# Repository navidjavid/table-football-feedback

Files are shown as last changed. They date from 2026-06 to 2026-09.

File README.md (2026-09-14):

# Table Football Feedback System ⚽

A smart foosball table built for the UbiLab university course. The table
identifies players by RFID, tracks the ball and score in real time, shows
match status on an on-cabinet LCD per side, and streams everything live
to a web dashboard hosted on a Raspberry Pi 4 — no internet connection
required, the Pi runs its own WiFi hotspot.

This repo contains **two independently-runnable projects**:

| Part | Where | Runs on | Language |
|---|---|---|---|
| Embedded firmware | `src/`, `include/`, `lib/` | Raspberry Pi Pico 2 W ×2 | C (Pico SDK) |
| Server + dashboard | `server/` | Raspberry Pi 4 | Python (Flask) |

They talk to each other over MQTT/WiFi — but the two Picos also talk
**directly to each other** over a shared I2C bus, so registration keeps
working even with no Pi/WiFi present at all (see §3).

---

## 1. System overview

```
 ┌──────────────┐                 ┌──────────────────────┐   ┌──────────────────────┐
 │ Ball tracker │────I2C (shared)▶│  Side A PCB           │   │  Side B PCB           │
 │ (external,   │────────────────▶│  Pico 2W + RFID +     │◀─▶│  Pico 2W + RFID +     │
 │  other team) │  both boards    │  display (PRIMARY)    │I2C│  display (SECONDARY)  │
 └──────────────┘  listen         └───────────┬──────────┘   └──────────┬────────────┘
                                               │ MQTT/WiFi                │ MQTT/WiFi
                                               ▼                          ▼
                                   ┌─────────────────────────────────────────────┐
                                   │              Raspberry Pi 4                  │
                                   │  WiFi hotspot "TableFootball"                │
                                   │  Mosquitto MQTT broker                       │
                                   │  Flask web app (SSE) + SQLite (WAL)          │
                                   └───────────────────┬───────────────────────────┘
                                                       │ HTTP / SSE
                                                       ▼
                                           Any phone/laptop on the hotspot —
                                           live dashboard, player profiles,
                                           admin panel, tournament brackets
```

**Two independent PCBs, one per side** — each has its own Pico 2 W, PN532
RFID reader, and EA DOGL128 display. Both boards listen to the same
shared I2C bus from the ball-tracker hardware. Exactly one board is
configured `PICO_ROLE_PRIMARY` (owns reporting ball position/score/state
to the Pi); the other only reports its own side's RFID taps + heartbeat —
this avoids the server ever getting duplicate/racing data from both
boards for the same table.

**Data flow, end to end:**

1. A player taps an RFID card on either side's own PN532 reader.
2. That board reads the UID over SPI, registers it locally (own side's
   roster, up to 2 players for 2v2), and:
   - broadcasts it directly to the **sibling board** over the shared I2C
     bus (a board briefly becomes I2C master to send this — see §3),
     so the other side learns about it **with no Pi/WiFi involved**;
   - publishes it to the Pi over MQTT, which is authoritative for
     identity/history — it resolves the UID against its own SQLite
     database (or creates a guest), decides when the match should
     start, and echoes the resolved name back.
3. The primary board republishes ball x/y/speed/score at ~12 Hz from the
   shared I2C feed; the dashboard renders this as a moving dot on a mini
   pitch.
4. Goals are detected locally (baseline-diffed against the ball
   tracker's own score fields, not trusted directly) on **both** boards
   independently, each updating its own display; the primary board's
   published state drives the dashboard's "GOAL!" animation.
5. At game end, the Pi saves the full match (mode, score, players,
   fastest shot, winner) to SQLite — shows up in player profiles, match
   history, and tournament brackets.
6. If a table gets stuck in `GAME_PLAYING` with no update for 45s (a
   board crashed/rebooted mid-match), the Pi's own watchdog auto-abandons
   it — so a later reconnect never resumes a long-dead game.

`[PICTURE: photo of the assembled table — both enclosures, PN532s, LCDs visible]`

---

## 2. Physical components & wiring

### Hardware list (×2, one set per side)

- **Raspberry Pi Pico 2 W** — WiFi, RFID, display, local game logic
- **PN532 NFC/RFID reader module**, configured in **SPI mode** (DIP
  switches: SEL0=OFF, SEL1=ON)
- **EA DOGL128L-6** graphic LCD, 128×64, reflective (no backlight),
  driven with **bit-banged SPI** (hardware SPI caused timing issues on
  this clone)
- A custom 3D-printed enclosure (front panel + back shell,
  `hardware/enclosure/` in a sibling directory to this repo — not
  version-controlled here) with a display window and a cable
  pass-through for the shared I2C bus
- RFID cards, one per player — UID is the player's identity end to end

Plus shared infrastructure:
- An external **ball-tracker** (built by another team) that writes ball
  position packets over I2C to both boards
- **Raspberry Pi 4** (any RAM tier) + microSD (16 GB+) + 5V/3A USB-C
  power supply — runs the WiFi hotspot, MQTT broker, and Flask server

`[PICTURE: each component individually — Pico board, PN532 module with DIP switches labeled, EA DOGL128 display, an assembled enclosure, an RFID card]`

### Real-world table dimensions

The physical table is **140 cm long × 76 cm wide**. The dashboard's
field visualization is intentionally drawn at this exact 140:76 aspect
ratio (`server/static/style.css`, `.field { aspect-ratio: 140 / 76; }`),
and ball coordinates are normalized to a 0–1000 × 0–500 grid before
being sent over MQTT so the same ratio holds end to end.

`[PICTURE: top-down schematic of the table with dimensions labeled, goal positions marked]`

### Pin connections — per side board

| Component | Signal | Pico GPIO | Physical pin |
|---|---|---|---|
| PN532 (SPI1) | SCK | GP10 | 14 |
| | MOSI | GP11 | 15 |
| | MISO | GP12 | 16 |
| | NSS/CS | GP13 | 17 |
| | RSTO | GP15 | 20 |
| | VCC / GND | 3.3V / GND | 36 / 38 |
| EA DOGL128 (bit-bang SPI) | SI (MOSI) | GP19 | 25 |
| | SCL (SCK) | GP18 | 24 |
| | A0 (data/cmd) | GP20 | 26 |
| | RST | GP21 | 27 |
| | CS1B | GP17 | 22 |
| Shared ball-tracker I2C bus | SDA | GP4 | 6 |
| | SCL | GP5 | 7 |

The display additionally needs **9 capacitors** for its internal charge
pump (5×1µF on V0–V4, 3×1µF on the CAP1/2/3 chain, 4.7µF on VOUT) — see
[`docs/hardware_connections.md`](docs/hardware_connections.md) for the
full, datasheet-verified capacitor wiring table; it will not power on
without them, and the topology is easy to get wrong (this project did,
once, before it was corrected).

The shared I2C bus needs **4.7kΩ pull-ups** on both SDA and SCL, and all
boards (both side PCBs + the ball tracker) must share a common GND.

`[PICTURE: wiring diagram / breadboard schematic showing all of the above]`

### PCB layout (KiCad)

The per-side board above is laid out in KiCad as
[`PCB/ubi_lab.kicad_sch`](PCB/ubi_lab.kicad_sch) +
[`PCB/ubi_lab.kicad_pcb`](PCB/ubi_lab.kicad_pcb) — open both together in
**KiCad 10**. It's a two-layer, 1.6 mm board with a **76 × 68 mm** outline,
carrying a socket footprint for a Pico-family board on the back plus three
connectors: `J1` (8-pin, PN532, fed from the board's 3.3V rail), `J2`
(40-pin, EA DOGL128L-6), and `J3` (4-pin, labeled `I2C_SIMULATOR` — VBUS/
GND/SDA/SCL on pins 1–4, for bench-testing against `test_i2c_simulator`
before the real ball tracker is wired in). `R1`/`R2` are the 4.7kΩ I2C
pull-ups called out above.

A few things to confirm before sending a board to fab or assembling one:

- The custom `ubi_lab:RaspberryPi_Pico_Socket_THT` footprint is embedded
  in the PCB, but its source library isn't in this repo — KiCad will need
  it to re-sync the PCB from schematic edits.
- The symbol/footprint say `RaspberryPi_Pico_W`, and the socket
  footprint's own description also mentions Pico 2 W — double check the
  exact variant, header orientation, and display-module/connector mating
  against the physical parts on hand.
- Schematic and PCB disagree on some capacitor reference designators
  (e.g. a PCB ref like `1µF7` vs. the schematic's `C` prefix) — run
  KiCad's ERC/DRC and reconcile annotations before fabrication.

### Software-side bus configuration

| Parameter | Value |
|---|---|
| SPI1 (PN532) speed | 1 MHz |
| I2C0 speed | 9600 baud |
| I2C slave address | `0x42` (shared by both side boards — see §3) |
| Display contrast | `0x13` |

Full pinout reference: [`docs/hardware_connections.md`](docs/hardware_connections.md).

---

## 3. Embedded firmware (Raspberry Pi Pico)

Built with the **Pico SDK 2.2.0**, targeting `pico2_w`, using **lwIP in
polling mode** (`NO_SYS=1` — no RTOS, everything runs from one
`while(true)` loop with `cyw43_arch_poll()` keeping WiFi/MQTT alive).

The **same firmware image** runs on both side boards — which side/role a
board plays is a compile-time config block at the top of `src/main.c`:

```c
#define MY_SIDE            'A'   // 'A' on this board, 'B' on the other
#define PICO_ROLE_PRIMARY  1     // 1 on exactly ONE board
#define PICO_ID    "pico-side-a" // must be unique per board
```

Flip these three, rebuild, and flash the other board.

### Source layout

| File | Responsibility |
|---|---|
| `src/main.c` | WiFi connect (with on-screen boot status), MQTT init, main loop |
| `src/rfid_handler.c` + `lib/pn532/pn532.c` | PN532 SPI driver + tap-debounce state machine |
| `src/i2c_comms.c` | Ball-position ring buffer **and** the offline peer-tap link between the two boards (see below) |
| `src/game_logic.c` | Local game state machine (`GAME_WAITING` → `GAME_PLAYING` → `GAME_OVER`), up to 2 players/side, goal detection, fastest-shot tracking |
| `src/display_manager.c` + `lib/ea_dogl128/` | Renders game state to the on-cabinet LCD |
| `src/pico_mqtt.c` + `include/pico_mqtt.h` | lwIP raw MQTT client wrapper — connects (with a Last-Will-Testament), publishes heartbeat/RFID/state/ball, subscribes to player/sync/rfid/cmd |
| `lwipopts.h` | lwIP buffer/pool sizing — tuned specifically to survive MQTT's keep-alive timers (see bug notes below) |

### Offline board-to-board link (no Pi/WiFi required)

Both boards need to know about **both** sides' registered players, but
cross-board MQTT sync only works when the Pi is reachable — and the PCBs
are already assembled with no spare wiring for a dedicated link. Instead,
the two boards share the same physical I2C bus the ball tracker uses:

- The ball tracker is the bus's only permanent master, always **writing**
  to address `0x42`; both boards listen there as slaves (a
  write-only-broadcast trick — see `include/i2c_comms.h`).
- When a card taps on one side, that board briefly becomes the I2C
  master itself (`i2c_slave_deinit()` → write → `i2c_slave_init()`,
  the Pico SDK's documented idiom for this) and writes a short 9-byte
  message to that same shared address. The sibling board, still
  listening normally, receives it — distinguished from ball-data packets
  purely by a different sync header.
- Standard I2C multi-master arbitration handles the rare case of
  colliding with the ball tracker's own write; a lost attempt is simply
  dropped (a tap is a one-off, low-frequency event, so this is an
  accepted low-stakes failure mode).

MQTT's `/rfid` topic (subscribed by both boards) is a second, best-effort
channel carrying the same information when the Pi is present — the I2C
link is what makes registration work **at all** with no Pi/WiFi.

### RFID → MQTT + I2C flow

1. `rfid_handler_scan()` polls the PN532 over SPI; a debounce window
   avoids re-firing on the same card sitting on the reader.
2. On a fresh tap, `game_lookup_player()` checks a small hardcoded
   table of known UIDs → names (demo roster: Alice, Bob, Carol, Dave)
   purely so the **local LCD** can show a name immediately.
3. The tap is registered locally (own side, next open slot), broadcast
   to the sibling board over I2C, and published to
   `tablefootball/table/<id>/rfid`. The Pi is the identity authority —
   it resolves the UID against its own SQLite `players` table and
   echoes the resolved name + slot back over
   `tablefootball/pico/<id>/player`.

### Ball tracking → MQTT flow

The ball tracker writes a 20-byte binary packet over I2C
(`SYNC_A SYNC_B x y prev_x prev_y field_w field_h speed possession
score_a score_b`, see `include/i2c_comms.h`). `i2c_comms_poll()` drains
this from a ring buffer filled by an I2C-slave interrupt handler — the
same ring buffer also carries the peer-tap messages above, distinguished
by sync header. `game_update()` diffs the embedded score against its
last-seen baseline to detect goals (rather than trusting the raw score
directly), and the ball position is rescaled to a 0–1000×0–500 grid
before the **primary** board publishes it on
`tablefootball/table/<id>/ball` at roughly 12 Hz.

`[PICTURE: serial console screenshot showing RFID tap + MQTT publish logs]`

### MQTT topics

**Published by each Pico:**

| Topic | Rate | Payload |
|---|---|---|
| `tablefootball/pico/<id>/heartbeat` | every 5s | online status, IP, firmware version, uptime |
| `tablefootball/table/<id>/rfid` | on tap | UID, side, slot |
| `tablefootball/table/<id>/state` | ~1/s, primary only | score, mode, fastest shot, winner (on GAME_OVER) |
| `tablefootball/table/<id>/ball` | ~12 Hz, primary only | x, y, speed |
| `tablefootball/pico/<id>/status` | LWT | `online:false`, set on disconnect |

**Subscribed by each Pico** (the Pi is source of truth for identity/state,
but the board must never depend on it being reachable — see §"Offline
board-to-board link" above):

| Topic | Purpose |
|---|---|
| `tablefootball/pico/<id>/player` | Authoritative name for a resolved tap |
| `tablefootball/table/<id>/sync` | Full roster + score/state snapshot (retained) — reconciles admin-driven registration changes, which produce no RFID tap at all |
| `tablefootball/table/<id>/rfid` | The sibling board's own taps (same topic it publishes to) |
| `tablefootball/pico/<id>/cmd` | Admin-panel commands: identify / reset_match / clear_players / show_message |

### Bugs worth knowing about (and their fixes)

These came up while building this firmware and are good examples of how
easy it is to silently break shared resources or drop a field across a
protocol boundary:

1. **I2C bytes dropped during every RFID scan.** `rfid_handler.c`
   disables `I2C0_IRQ` for the duration of `pn532_read_card()` to keep
   the I2C slave handler from interfering with SPI timing. But PN532's
   internal "wait for ready" polling loop can run for up to ~250ms per
   scan, and the IRQ stayed off that whole time — so every ball-position
   byte arriving during a card scan was lost. **Fix:** the wait loop now
   masks `I2C0_IRQ` only for the few microseconds of the actual SPI
   status read, unmasked during each 1ms sleep in between.
2. **`*** PANIC *** sys_timeout` crash.** lwIP's default
   `MEMP_NUM_SYS_TIMEOUT` pool wasn't enough once MQTT's keep-alive timer
   joined it. **Fix:** `lwipopts.h` explicitly sets it to 16.
3. **Admin dashboard commands did nothing on real hardware.** The server
   published to `tablefootball/pico/<id>/cmd` from the start, but the
   firmware never subscribed to that topic at all — every "Identify" /
   "Reset Match" / "Message" button silently no-op'd. Fixed by actually
   subscribing and dispatching (see `on_pi_cmd()` in `main.c`).
4. **A 2v2 name-correction bug.** The Pi's per-tap name resolution always
   corrected roster slot 1, no matter which slot the response was
   actually about — invisible in 1v1 (only one slot exists), but
   resolving a *second* player's name would silently overwrite the
   first player's name too. Fixed by having the server include (and the
   firmware use) the actual slot number in that message.
5. **A NULL-pointer crash with no Pi present.** If the Pi's hotspot
   simply doesn't exist at boot, `mqtt_app_init()` is never called, so
   the internal MQTT client stays `NULL` — but every heartbeat/RFID
   publish still tried to reconnect through it, crashing on first use.
   Fixed with a guard so every publish path is a safe no-op with no
   client. This is exactly the "must work fully offline" requirement,
   caught by testing the actual no-Pi scenario rather than just a
   dropped-connection one.

### Building & flashing

```bash
# Requires the Pico SDK (2.2.0) + arm toolchain + CMake + Ninja.
mkdir build && cd build
cmake -G Ninja ..
ninja table-football
```

Flip `MY_SIDE`/`PICO_ROLE_PRIMARY`/`PICO_ID` at the top of `src/main.c`
(see above), rebuild, and repeat for the other side's board.

Hold **BOOTSEL**, plug the Pico in (it mounts as a USB drive), then drag
`build/table-football.uf2` onto it.

There are also standalone test targets for bringing up hardware in
isolation without the full stack — useful when debugging a single
peripheral (see `tests/`):

| Target | Tests |
|---|---|
| `test_i2c_simulator` | Fakes ball movement over I2C — a second Pico can stand in for the real ball tracker |
| `test_pn532` | Raw PN532 SPI bring-up (firmware version + card polling), independent of the rest of the stack |
| `test_pn532_lib` | Same, using the actual `lib/pn532/pn532.c` driver the main firmware uses |
| `test_i2c_scan` | Protocol-independent I2C bus scanner (bypasses custom SPI/I2C code entirely — useful for "is this chip even alive" questions) |

---

## 4. Server & dashboard (Raspberry Pi 4)

Everything in `server/` — see [`server/README.md`](server/README.md)
for the full setup walkthrough, troubleshooting table, and MQTT
cheat-sheet. Summary:

### Stack

- **NetworkManager hotspot** — the Pi broadcasts its own WiFi network
  (`TableFootball`), so the whole system works with zero internet/router
  dependency.
- **Mosquitto** — local MQTT broker on port 1883.
- **Flask** (`server/app.py`) — HTTP routes, admin auth, and an
  `/events` SSE endpoint that streams `table_state`, `ball_position`,
  `player_update`, and `pico_status` events to every open browser.
- **`mqtt_client.py`** — subscribes to `tablefootball/#`, owns the
  authoritative game state machine per table:
  `WAITING → PLAYERS_REGISTERING → GAME_PLAYING → GAME_OVER / ABANDONED`,
  and writes everything through to SQLite.
- **SQLite (WAL mode)** — `players`, `live_tables`, `live_players`,
  `matches`, `match_players`, `pico_devices`, `tournaments` /
  `tournament_entries` / `tournament_matches`.
- **A watchdog thread** — marks a Pico offline after 30s of silent
  heartbeat, and (separately) auto-abandons a table stuck in
  `GAME_PLAYING` with no `/state` update for 45s, so a board that
  crashed mid-match doesn't leave a permanently "live" game behind.

### Dashboard (`server/static/script.js`, `templates/index.html`)

- One page, no install — any device on the hotspot opens
  `http://tb.local`.
- Real-time via SSE, with an automatic 5-second polling fallback if the
  stream drops.
- Each table card shows: player name(s) per side (colored pill, with a
  Guest/Registered badge, up to 2 names per side for 2v2), live score in
  large digits, a mini pitch drawn at the table's real 140:76 ratio with
  goal markers at each end and a live ball dot, best-shot speed, and a
  winner/abandoned banner.
- **Goal celebration:** when a side's score increases, a 2-second
  animated "GOAL!" banner pops over the pitch, colored and named for
  the scoring side.
- Clicking a row in the players table opens that player's full profile
  page (`/player/<uid>`) — match history and a fastest-shot-over-time
  chart.

`[PICTURE: screenshot of the dashboard mid-match, ideally caught mid-goal-animation]`

### Player profiles, admin & tournaments

- `/player/<uid>` — games/wins/losses, best shot, full match history,
  and (browser permitting) a fastest-shot-over-time chart.
- `/admin` — rename guest players into registered ones, watch Pico
  online/offline status, per-Pico commands (identify/reset/clear/message —
  see §3), and a tournament manager: create a bracket, add entries,
  auto-generate a single-elimination tree (byes go to the top seeds,
  never bye-vs-bye), assign a pending match to a live table, and watch
  it auto-advance as matches finish. Basic auth via `.env`'s
  `ADMIN_PASSWORD`.

`[PICTURE: screenshot of a player profile page, the admin panel, and a tournament bracket]`

### Try it without real Picos

```bash
cd server
python tests/simulate_game.py          # full match: heartbeat → register → goals → GAME_OVER
python tests/simulate_rfid.py DBEF7005 A
```

---

## 5. Known limitations / next steps

- **Offline match history sync** — a match played entirely while a Pico
  is disconnected from the Pi never reaches match history/stats once it
  reconnects (registration itself works fully offline via the I2C peer
  link in §3; only the *server-side record* of that match is missing).
- **Local "tap out" while offline** — tapping an already-seated card is
  meant to deregister that player (the server already treats a repeat
  tap this way); the local firmware currently just ignores a repeat tap
  as a duplicate, so leaving mid-game only works once the Pi is
  reachable to correct it via `sync`.
- **Self-service player registration** — a truly unknown card currently
  becomes a "Guest" automatically; naming a guest still requires the
  admin panel rather than a prompt on the dashboard itself.
- **Real ball tracking** — the ball-tracker hardware is owned by another
  team; this repo only defines the I2C packet format it must produce.
- **HTTPS / session expiry** — fine on a closed local hotspot, but would
  need hardening before exposing the admin panel beyond the LAN.

`[PICTURE: optional roadmap graphic]`

---

## Repository layout

```
table-football/
├── src/                  Pico firmware: main.c, rfid_handler.c, i2c_comms.c,
│                         game_logic.c, display_manager.c, pico_mqtt.c
├── include/              Public headers for the above
├── lib/
│   ├── pn532/            PN532 SPI driver
│   └── ea_dogl128/       EA DOGL128 display driver
├── tests/                Standalone Pico test harnesses (see §3 table)
├── PCB/                  KiCad schematic + PCB for the per-side controller board (see §2)
├── docs/
│   ├── hardware_connections.md   Full pinout + capacitor wiring reference
│   └── hardware_setup.md
├── lwipopts.h            lwIP buffer/pool sizing (tuned for MQTT keep-alive)
├── CMakeLists.txt        Builds table-football + all standalone test targets
└── server/               Flask + MQTT + SQLite server and dashboard
    ├── app.py, mqtt_client.py, database.py, state.py, config.py
    ├── templates/, static/        Dashboard, player profile, admin UI
    ├── tests/                     MQTT simulators (run the server without real Picos)
    ├── scripts/                   setup_hotspot.sh, backup_db.sh
    └── systemd/                   football.service for boot-time autostart
```

The 3D-printable enclosure design (`enclosure.scad` + exported STLs)
lives in a sibling `hardware/enclosure/` directory outside this repo,
not version-controlled here.

## Prerequisites

- [Pico SDK](https://github.com/raspberrypi/pico-sdk) 2.2.0 + arm-none-eabi
  toolchain + CMake + Ninja, for the firmware.
- Python 3.11+ and Mosquitto, for the server (see
  [`server/README.md`](server/README.md) for the full Raspberry Pi setup).

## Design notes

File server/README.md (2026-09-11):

# Table Football — Raspberry Pi Server

The Raspberry Pi 4 acts as the central hub for the table football
project. It runs as a WiFi hotspot, MQTT broker, Flask web server, and
SQLite database, all starting automatically on boot.

```
+----------------+        +-------------+         +-------------+
| Pico Side A    |  MQTT  |             |  SSE    | Phone /     |
| (RFID, LCD)    | <----> |   Pi 4      | ------> | Browser     |
+----------------+        |             |         +-------------+
                          | mosquitto   |
+----------------+        | flask app   |
| Pico Side B    |  MQTT  | sqlite (WAL)|
| (RFID, LCD)    | <----> |             |
+----------------+        +-------------+

Hotspot: SSID "TableFootball"  -  192.168.4.1
Browser: http://tb.local  (or http://192.168.4.1)
MQTT:    192.168.4.1:1883
```

## What this folder contains

```
server/
├── app.py              Flask app + HTTP routes + SSE + startup wiring
├── mqtt_client.py      MQTT subscribe/publish + game-state handlers
├── database.py         All SQLite access (thread-local connections, WAL)
├── state.py            In-memory live snapshots + SSE fan-out
├── config.py           Loads .env, configures rotating-file logging
├── requirements.txt    Python deps
├── .env.example        Copy to .env and fill in
├── templates/          Jinja templates (dashboard, player, admin)
├── static/             CSS + JS
├── tests/              MQTT simulators for testing without real Picos
├── scripts/            setup_hotspot.sh, backup_db.sh
└── systemd/            football.service unit + ops notes
```

## Hardware list

- Raspberry Pi 4 (any RAM tier) with Raspberry Pi OS **Bookworm**
- microSD card (16 GB+)
- 5 V / 3 A USB-C power supply
- Two Raspberry Pi Pico 2 W per table (firmware lives in `../src`)

## Setup (one-shot, ~10 min)

```bash
# 1. Flash Raspberry Pi OS Bookworm Lite to the SD card, boot, ssh in.

# 2. Hotspot
sudo bash scripts/setup_hotspot.sh "TableFootball" "football2026"
# (overrides: setup_hotspot.sh <ssid> <password>)

# 3. Mosquitto MQTT broker
sudo apt update
sudo apt install -y mosquitto mosquitto-clients sqlite3
sudo tee /etc/mosquitto/conf.d/football.conf >/dev/null <<'EOF'
listener 1883
allow_anonymous true
max_connections 20
EOF
# NOTE: `listener` must come FIRST. mosquitto applies any settings declared
# before a `listener` line to its implicit default listener; if `listener`
# comes last, you end up with two listeners both bound to 1883 and the
# broker fails with "Address already in use" against itself.
sudo systemctl enable mosquitto
sudo systemctl restart mosquitto

# 4. Python env
cd /home/pi/Desktop/server
python3 -m venv venv
source venv/bin/activate
pip install -r requirements.txt

# 5. .env
cp .env.example .env
python -c "import secrets; print('SECRET_KEY=' + secrets.token_hex(32))" >> .env
nano .env             # change ADMIN_PASSWORD

# 6. systemd
sudo cp systemd/football.service /etc/systemd/system/
sudo systemctl daemon-reload
sudo systemctl enable football
sudo systemctl start football

# 7. Reboot to confirm everything starts automatically.
sudo reboot
```

After reboot, connect a phone or laptop to the **TableFootball** WiFi
and open <http://tb.local>. The admin panel is at
<http://tb.local/admin>.

## Running in development (on any machine)

```bash
cd server
python3 -m venv venv
source venv/bin/activate    # on Windows: venv\Scripts\activate
pip install -r requirements.txt
cp .env.example .env        # then fill in SECRET_KEY
python app.py
```

You'll need a local mosquitto running on `localhost:1883`. On Windows
you can install one via Chocolatey (`choco install mosquitto`) or run
the simulators against a Pi over your LAN by setting `MQTT_HOST` in
`.env`.

## Try it without real Picos

In another terminal (with the server already running):

```bash
# A complete match (heartbeat → register → goals → GAME_OVER)
python tests/simulate_game.py

# Or piece-by-piece:
python tests/simulate_heartbeat.py sim-A 1 A primary
python tests/simulate_rfid.py DBEF7005 A
python tests/simulate_rfid.py 4C069804 B
```

Open the dashboard while the simulator runs to watch the table card
update live.

## MQTT topic cheat-sheet

| Direction | Topic | QoS | Retain | Notes |
|---|---|-----|---|---|
| Pico → Pi | `tablefootball/pico/<id>/heartbeat` | 0 | no  | every 5s |
| Pico → Pi | `tablefootball/pico/<id>/status` | 1 | yes | LWT, `online:false` |
| Pico → Pi | `tablefootball/table/<id>/rfid` | 1 | no  | card taps |
| Pico → Pi | `tablefootball/table/<id>/state` | 1 | no  | score / GAME_OVER (primary only) |
| Pico → Pi | `tablefootball/table/<id>/ball` | 0 | no  | 10 Hz ball position |
| Pi → Pico | `tablefootball/pico/<id>/player` | 1 | no  | response after RFID |
| Pi → Pico | `tablefootball/table/<id>/sync` | 1 | yes | canonical table state |
| Pi → Pico | `tablefootball/pico/<id>/players_list` | 1 | yes | full {uid, name} list for offline mode |
| Pi → Pico | `tablefootball/pico/<id>/cmd` | 1 | no  | identify / reset / message |

Manual probe (handy when wiring up Picos):

```bash
# Watch every message on the broker.
mosquitto_sub -h localhost -t 'tablefootball/#' -v

# Fake an RFID tap.
mosquitto_pub -h localhost -t tablefootball/table/1/rfid \
  -m '{"v":1,"pico_id":"sim-A","table_id":1,"side":"A","slot":1,"uid":"DBEF7005","event":"card_tapped"}'
```

## Daily operations

- **Change the admin password:** edit `.env`, then `sudo systemctl restart football`.
- **Backup the DB:** run `bash scripts/backup_db.sh` (or wait for the cron entry below).
- **Daily backups at 04:00:** `crontab -e` and add
  ```
  0 4 * * * /home/pi/Desktop/server/scripts/backup_db.sh
  ```
  Backups live in `server/backups/` and are pruned after 7 days.
- **Tail logs:** `sudo journalctl -u football -f` or `tail -f logs/server.log`.

## Troubleshooting

| Symptom | First thing to check |
|---|---|
| mosquitto fails with "Address already in use" against itself | Check `/etc/mosquitto/conf.d/football.conf` — `listener 1883` must be the **first** line, before `allow_anonymous`/`max_connections`. See note in step 3 above. |
| Picos can't see the hotspot | `nmcli con show TableFootball-AP` then `nmcli con up TableFootball-AP` |
| Dashboard not updating | DevTools → Network → `/events` shows a `text/event-stream` that stays open |
| MQTT messages not arriving | `mosquitto_sub -h localhost -t 'tablefootball/#' -v` while triggering a tap |
| Server won't start | `sudo journalctl -u football -n 50` — most often a missing `SECRET_KEY` in `.env` |
| Players not appearing | confirm `pico_id` in `pico_devices` has a `table_id` assigned (or assign via /admin) |
| DB locked errors | `PRAGMA journal_mode` should be `wal`: `sqlite3 football.db "PRAGMA journal_mode"` |

## Known limitations (v1)

- Matches played while the Pico is offline are not synced back to the
  Pi when it reconnects. Offline play is supported on the Pico, but
  those matches don't reach the history.
- The server does not serve HTTPS — acceptable on the closed local
  hotspot, not for public exposure.
- Admin sessions never expire. Replace the session config (or move to
  a proper auth library) before exposing the panel outside the LAN.

## Future hooks (already wired)

- **Web NFC player lookup** — `GET /player/<uid>` and
  `GET /api/player/by-uid/<uid>` are live; a browser-side NFC scan can
  just navigate to the URL.
- **Tournaments** — `tournaments`, `tournament_entries`, and
  `tournament_matches` tables are created on first run. No UI yet, so a
  later migration is not required.

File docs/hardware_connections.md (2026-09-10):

# Table Football Feedback System — Hardware Connections

## Components

Final deployment is **two identical side boards** (not one main + one
simulator, as earlier revisions of this doc described) — each is:

- Raspberry Pi Pico 2W
- PN532 RFID Reader
- EA DOGL128L-6 Display (128x64 reflective LCD)

Both boards run the same firmware image (only a compile-time `MY_SIDE`/
`PICO_ROLE_PRIMARY` config differs — see the main README §3) and both
listen to the same shared I2C bus from an **external ball tracker**
(built by another team, feeds ball position packets only — see
`include/i2c_comms.h` for the packet format it must produce). The pin
tables below apply to each side board identically.

---

## 1. PN532 RFID Reader

**DIP Switch Setting (SPI mode):**
```
SEL0 = OFF  (switch 1 down)
SEL1 = ON   (switch 2 up)
```

| PN532 Pin | Pico 2W GPIO | Pico 2W Physical Pin |
|---|---|---|
| VCC | 3.3V | Pin 36 |
| GND | GND | Pin 38 |
| SCK | GP10 | Pin 14 |
| MOSI | GP11 | Pin 15 |
| MISO | GP12 | Pin 16 |
| NSS / CS  | GP13 | Pin 17 |
| RSTO | GP15 | Pin 20 |
| IRQ | — | Not connected |

---

## 2. EA DOGL128L-6 Display

### Signal Pins

| Display Pin | Signal | Pico 2W GPIO | Pico 2W Physical Pin |
|---|---|---|---|
| Pin 36 | SI (MOSI)| GP19 | Pin 25 |
| Pin 37 | SCL (SCK)| GP18 | Pin 24 |
| Pin 38 | A0 | GP20 | Pin 26 |
| Pin 39 | RST | GP21 | Pin 27 |
| Pin 40 | CS1B | GP17 | Pin 22 |

### Power Pins

| Display Pin | Signal | Connect To |
|---|---|---|
| Pin 35 | VDD | 3.3V |
| Pin 34 | VDD2 | 3.3V |
| Pin 26 | VSS | GND |
| Pin 33 | VSS | GND |

### Capacitors (required for internal charge pump)

| Connection | Value |
|---|---|
| Pin 21 (V0) ── GND | 1µF ceramic  |
| Pin 22 (V1) ── GND | 1µF ceramic  |
| Pin 23 (V2) ── GND | 1µF ceramic  |
| Pin 24 (V3) ── GND | 1µF ceramic  |
| Pin 25 (V4) ── GND | 1µF ceramic  |
| Pin 28 (CAP2P) ── Pin 27 (CAP2N)| 1µF ceramic  |
| Pin 31 (CAP3P) ── Pin 30 (CAP1N)| 1µF ceramic  |
| Pin 30 (CAP1N) ── Pin 29 (CAP1P)| 1µF ceramic  |
| Pin 32 (VOUT)  ── GND | 4.7µF ceramic or electrolytic (+ leg on pin 32 if electrolytic) |

> Total: 9 capacitors. All required. Missing any one will prevent the display from working.
>
> Note: V0–V4 are each an **independent** capacitor to GND (not a series chain between
> adjacent V pins), and CAP3P connects to CAP1N (not directly to GND) — CAP3P, CAP1N,
> and CAP1P form a single two-capacitor chain. An earlier version of this table had both
> of these wrong; this is the corrected, datasheet-verified wiring.

---

## 3. I2C Bus (Main Pico ↔ Simulator Pico)

| Signal | Main Pico | Simulator Pico |
|---|---|---|
| SDA | GP4 (Pin 6) | GP4 (Pin 6) |
| SCL | GP5 (Pin 7) | GP5 (Pin 7) |
| GND | GND | GND |

### Pull-up Resistors (required, place on either board)

```
3.3V ──[4.7kΩ]── SDA line
3.3V ──[4.7kΩ]── SCL line
```

### Power — Simulator Pico powered from Main Pico

| Main Pico | Simulator Pico  |
|---|---|
| VBUS (Pin 40)  | VSYS (Pin 39)  |
| GND | GND |

---

## 4. Complete GPIO Summary — Main Pico 2W

| GPIO | Physical Pin | Function | Connected To |
|---|---|---|---|
| GP4  | Pin 6 | I2C0 SDA | Simulator Pico GP4 |
| GP5  | Pin 7 | I2C0 SCL | Simulator Pico GP5 |
| GP10 | Pin 14 | SPI1 SCK | PN532 SCK |
| GP11 | Pin 15 | SPI1 MOSI | PN532 MOSI |
| GP12 | Pin 16 | SPI1 MISO | PN532 MISO |
| GP13 | Pin 17 | GPIO out (CS) | PN532 NSS/CS |
| GP15 | Pin 20 | GPIO out (RST) | PN532 RSTO |
| GP17 | Pin 22 | GPIO out (CS) | Display CS (pin 40)  |
| GP18 | Pin 24 | GPIO out (SCK) | Display SCL (pin 37) |
| GP19 | Pin 25 | GPIO out (MOSI)  | Display SI (pin 36)  |
| GP20 | Pin 26 | GPIO out (A0) | Display A0 (pin 38)  |
| GP21 | Pin 27 | GPIO out (RST) | Display RST (pin 39) |

---

## 5. Complete GPIO Summary — Simulator Pico 2W

| GPIO | Physical Pin | Function | Connected To |
|---|---|---|---|
| GP4  | Pin 6 | I2C0 SDA | Main Pico GP4 |
| GP5  | Pin 7 | I2C0 SCL | Main Pico GP5 |

---

## 6. Power Rail Summary

| Rail | Source | Powers |
|---|---|---|
| 5V (VBUS) | PC USB | Main Pico, then to Simulator Pico VSYS  |
| 3.3V | Main Pico regulator| PN532 VCC, Display VDD/VDD2 |
| GND | Common | All components |

> Total estimated current: ~175mA. Well within the 600mA limit of the Pico 2W regulator.

---

## 7. Software Configuration

| Parameter | Value  |
|---|---|
| SPI1 speed | 1 MHz  |
| I2C0 speed | 9600 baud |
| I2C slave address | 0x42 |
| Display contrast  | 0x13 |
| Display type | SPI (bit-bang, no hardware SPI) |
| RFID interface | SPI1 (hardware SPI) |

---

## Notes

- The EA DOGL128L-6 is the **reflective** variant — no backlight is possible or needed.
- The display uses **bit-bang SPI** (not hardware SPI) because hardware SPI timing caused issues with this clone variant.
- The PN532 **IRQ pin is not used** — the driver polls for card presence.
- The I2C slave IRQ is temporarily disabled during RFID transactions to prevent timing interference.
- Both Picos share a common GND — this is required for I2C to work correctly.

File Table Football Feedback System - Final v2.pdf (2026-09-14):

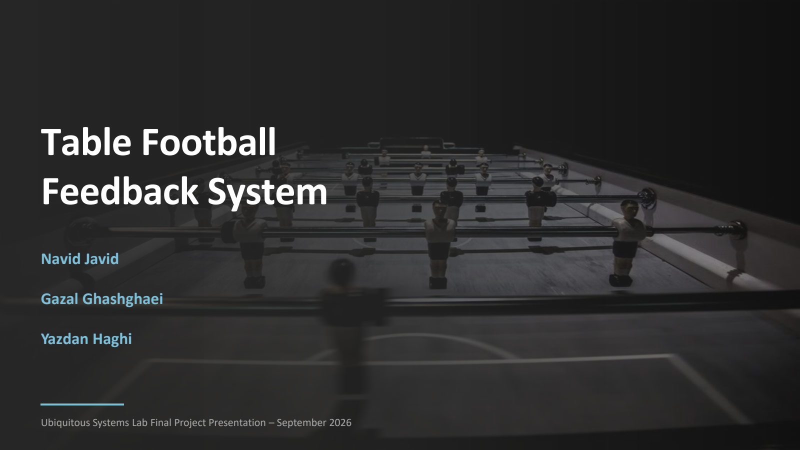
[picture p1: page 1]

# Table Football Feedback System

Ubiquitous Systems Lab Final Project Presentation – September 2026

## Navid Javid

## Gazal Ghashghaei

## Yazdan Haghi

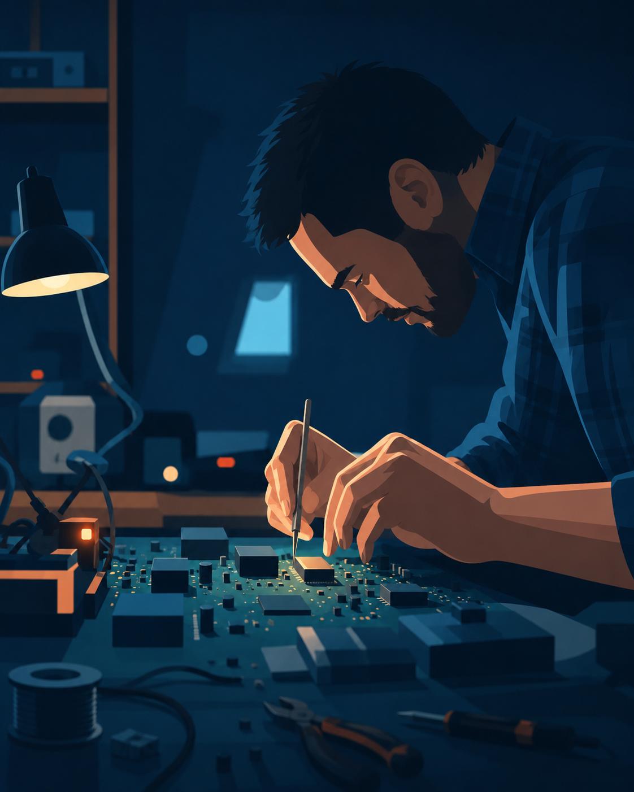
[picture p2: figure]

# Presentation Structure

## Main Sections

### Project Overview

### Physical Components & Dual Boards

### Online & Offline Operation

### Embedded Firmware & Software

### Hardware Design & PCB

### Game Modes: 1v1, 2v2 & Tournaments

### Dashboard & Admin Panel

### Remaining Future Work

This presentation covers the full system from hardware to software:

# What the Project Does

This project turns a normal table-football setup into a smart feedback system.

Each player identifies themselves by tapping an RFID/NFC card on their side. Each side's Pico reads the player identity, shares ball and score data with its sibling board over I2C, updates its local LCD, and sends live match information to a Raspberry Pi server.

The Raspberry Pi stores player and match data, manages the live dashboard, and allows users to view scores, player profiles, and game history.

# System Architecture

### How the Main Parts Work Together

## Layer 1

Device Layer

Two independent side-PCBs (one primary, one secondary) each read their own RFID reader and a shared ball-position feed, and coordinate directly with each other over I2C when the Pi is unreachable

## Layer 2

Communication &
Backend Layer

WiFi + MQTT carry table events to the Raspberry Pi, where server logic is the single source of truth for game state.

## Layer 3

Data & Presentation Layer | SQLite stores permanent match history while Flask + SSE push live updates to dashboards, profiles, and the admin
| panel.

# System Operation — Online Mode

### End-to-End Data Flow (Wi-Fi + MQTT)

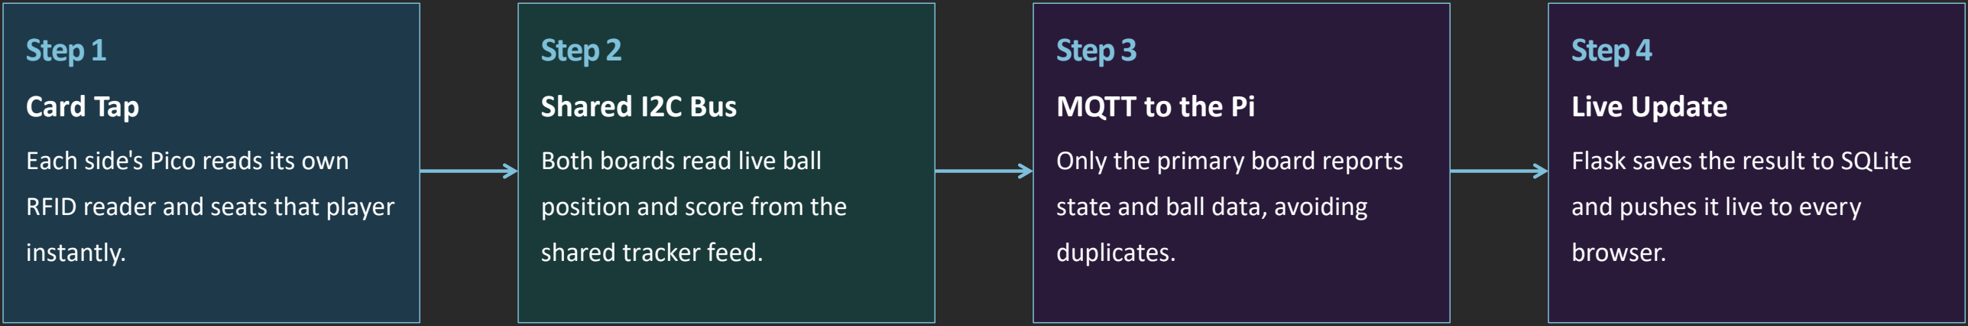
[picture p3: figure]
Step 1; Card Tap; Each side's Pico reads its own; RFID reader and seats that player; instantly.; Step 2; Shared I2C Bus; Both boards read live ball; position and score from the; shared tracker feed.; Step 3; MQTT to the Pi; Only the primary board reports; state and ball data, avoiding; duplicates.; Step 4; Live Update; Flask saves the result to SQLite; and pushes it live to every; browser.

Server as source of truth: while online, the Pi's database is authoritative for match history and player stats — the boards' own local game state is just the real-time display.

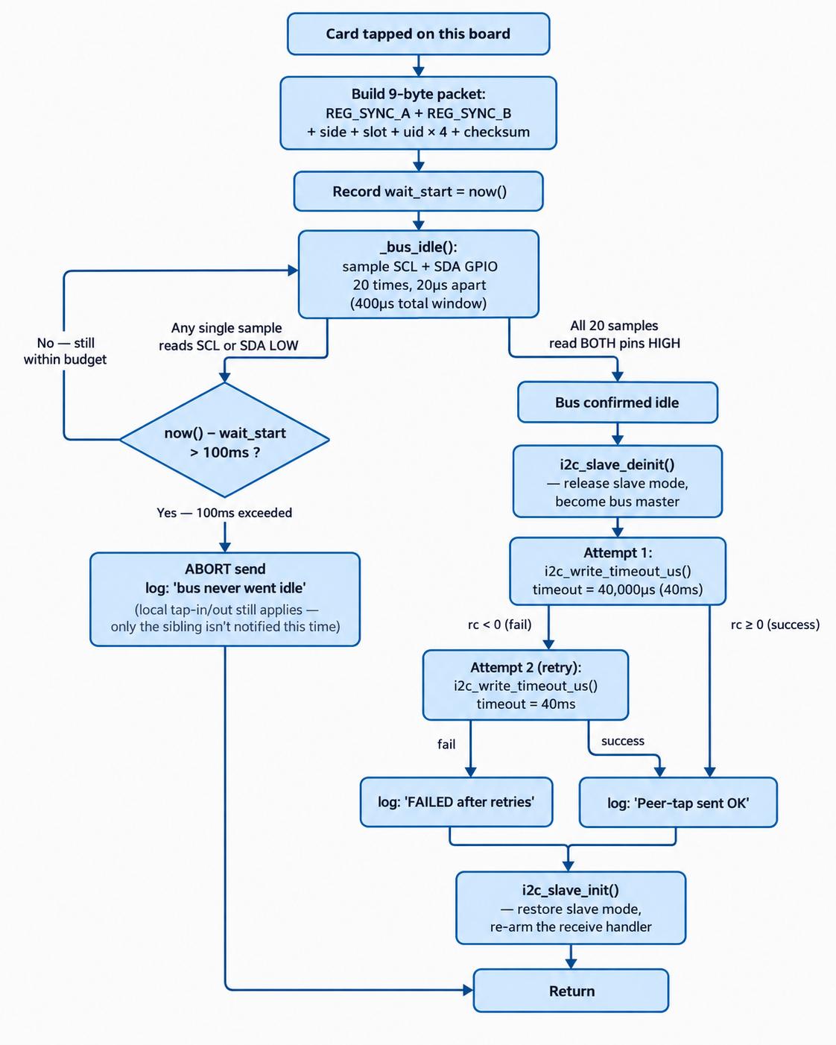
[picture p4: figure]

# Offline Mode & I2C Data Exchange

### Works With No Wi-Fi or Server

## Card Tap (Offline)

Each side's Pico reads its own RFID reader and registers the player locally

## Shared I2C Bus

The ball tracker and the two boards' own tap messages share the same wires; a board waits for a quiet moment on the bus before telling its sibling about a tap.

## Local Game State

Both boards track score, goals, and match-over entirely on-device — every decision is made locally, with no Pi involved at all.

## Local Name Directory

Player names come from a directory synced earlier from the Pi and saved on the board's own flash . Real names still show up offline, even after a power cycle.

# Embedded Firmware Structure

### Shared by Both Boards

main.c

The coordinator. Initializes Wi-Fi, MQTT, I2C, RFID, display, and game logic. Runs the main loop.

rfid_handler.c

Works with the PN532 driver and handles card tap detection for player identification.

i2c_comms.c

Receives ball data and relays peer-tap messages over the same shared I2C bus.

game_logic.c

Manages player registration, score updates, fastest-shot tracking, and game state transitions.

display_manager.c

Converts the current game state into screens for the LCD display.

pico_mqtt.c

Publishes live data to the Pi and applies admin commands (identify, reset, message) sent back.

One firmware image runs on both boards — a single compile-time flag decides which side and role a board takes on.

# Component Libraries

### Low-Level Drivers

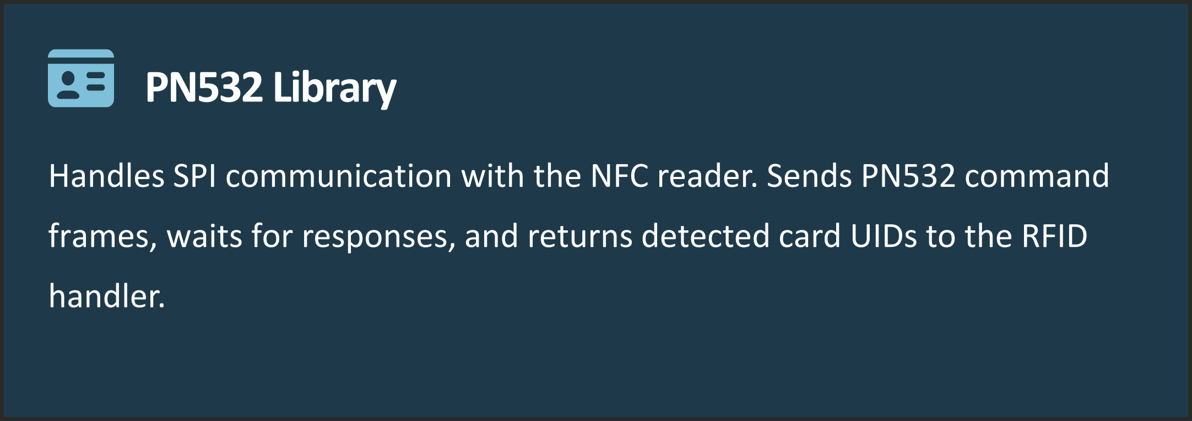
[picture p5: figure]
PN532 Library; handler.

Handles SPI communication with the NFC reader. Sends PN532 command frames, waits for responses, and returns detected card UIDs to the RFID

## EA DOGL128 Library

Manages the LCD framebuffer, drawing functions, text rendering, rectangles, lines, contrast control, and screen flushing.

Key Benefit: This separation is useful because the main game logic does not need to know the electrical details of the display or RFID reader. It only calls higher-level functions like "scan card" or "draw game screen."

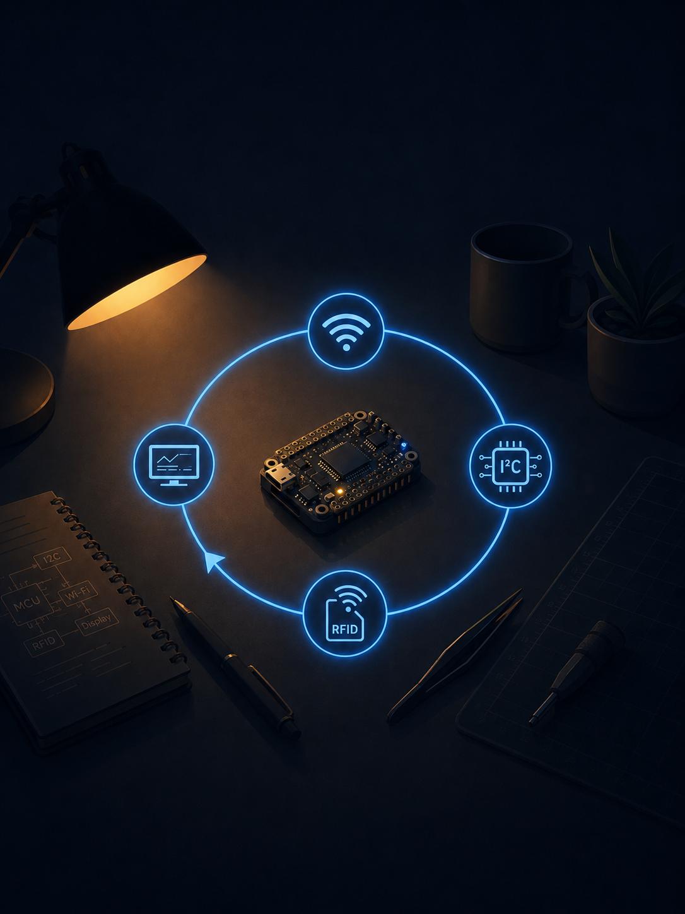
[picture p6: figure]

# Main Firmware Loop

### How the Pico Runs the System

## 1 Keep Connections Alive

Poll the WiFi/lwIP stack every loop iteration so the WiFi link and MQTT connection stay serviced.

## 2 Check I2C Ball Data

Update local game state from the shared feed; only the primary board forwards it to the Pi.

## 3 Check RFID Reader

If a new UID is detected, change player registration and publish an RFID event.

## 4 Refresh & Publish

Refresh the LCD and publish MQTT messages at controlled intervals. heartbeat every 5s, ball position ~12 times a second.

# Game Logic

### From Player Registration to Game Over

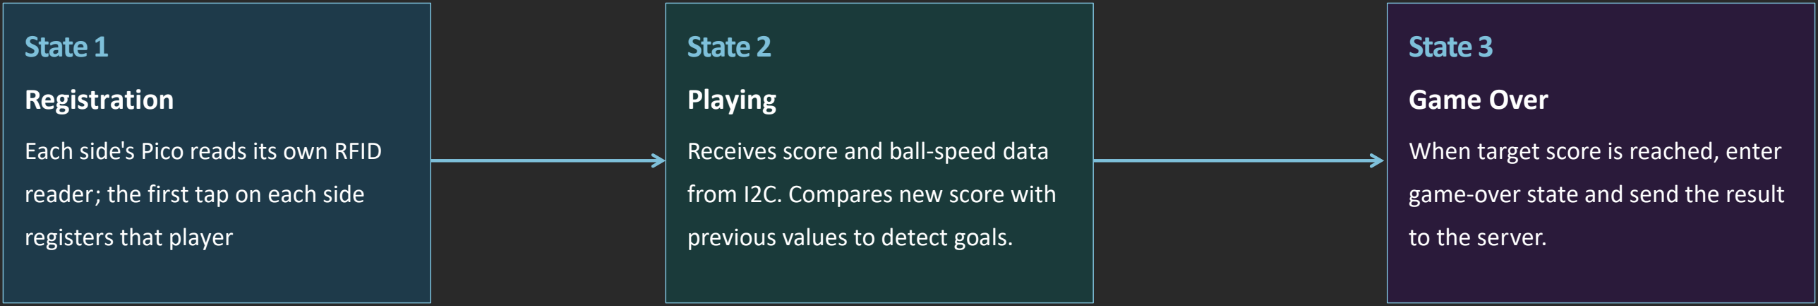
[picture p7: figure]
State 1; Registration; Each side's Pico reads its own RFID; reader; the first tap on each side; registers that player; State 2; Playing; Receives score and ball-speed data; from I2C. Compares new score with; previous values to detect goals.; State 3; Game Over; When target score is reached, enter; game-over state and send the result; to the server.

Works in 2v2 too: a side can hold two players; tapping an already-seated card again removes that player — even mid-match, which safely ends the match if a side empties.

# Communication Between Components

### Connection Types

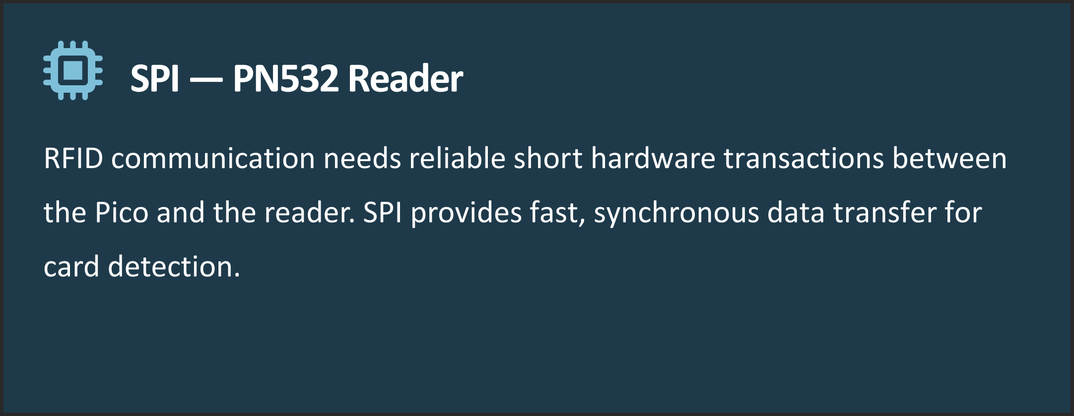
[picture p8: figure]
SPI — PN532 Reader; card detection.

RFID communication needs reliable short hardware transactions between the Pico and the reader. SPI provides fast, synchronous data transfer for

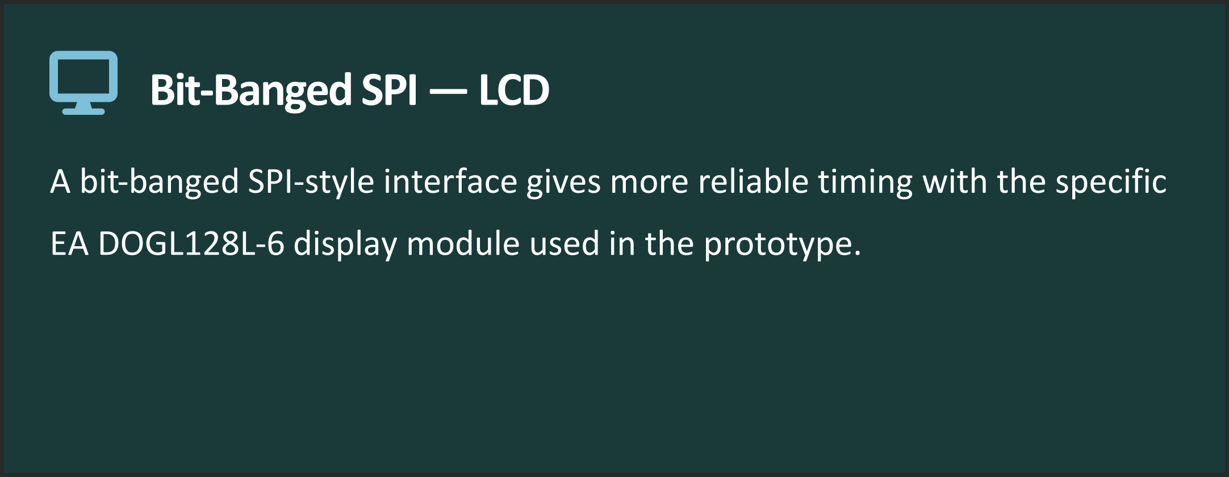
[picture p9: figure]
Bit-Banged SPI — LCD

A bit-banged SPI-style interface gives more reliable timing with the specific EA DOGL128L-6 display module used in the prototype.

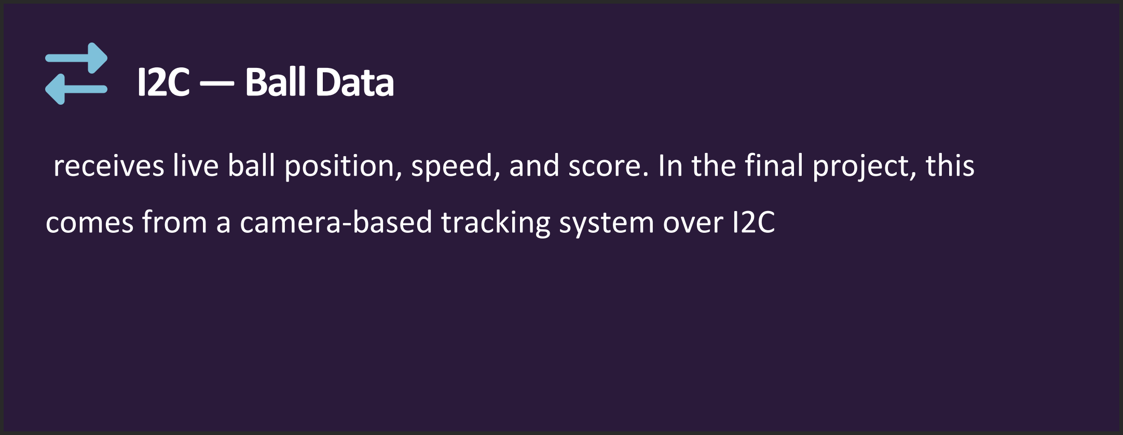
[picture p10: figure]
I2C — Ball Data

receives live ball position, speed, and score. In the final project, this comes from a camera-based tracking system over I2C

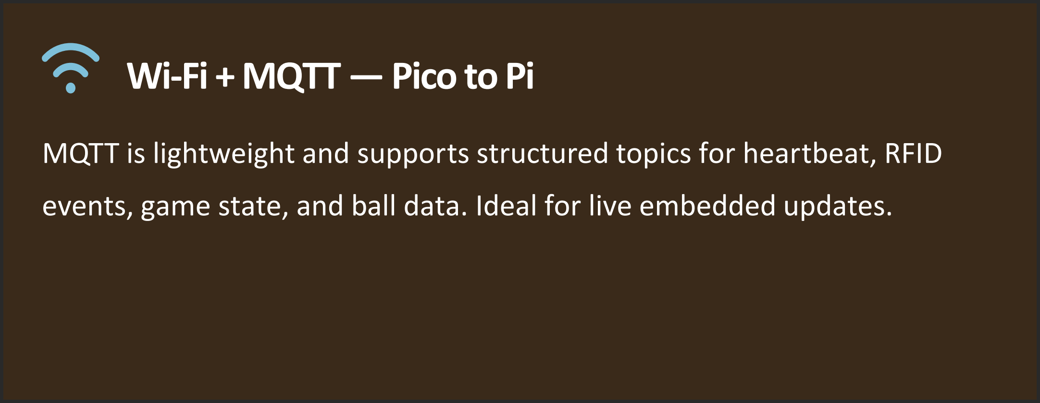
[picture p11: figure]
Wi-Fi + MQTT — Pico to Pi

MQTT is lightweight and supports structured topics for heartbeat, RFID events, game state, and ball data. Ideal for live embedded updates.

# Raspberry Pi Server Stack

### Server-Side Architecture

Receives all published messages from the Pico — heartbeat, RFID events, game state, ball data.

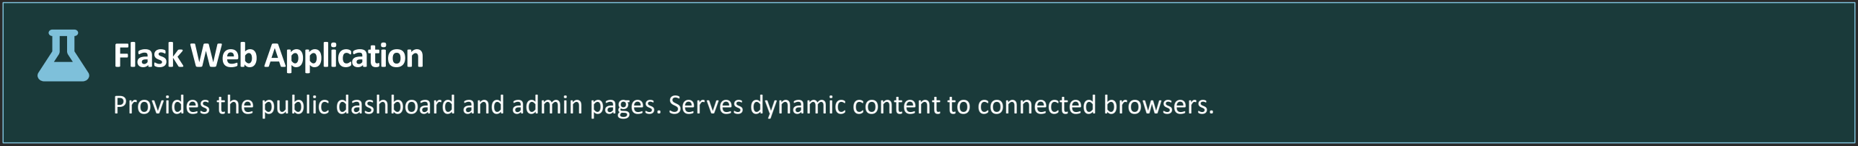
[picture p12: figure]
Flask Web Application

Provides the public dashboard and admin pages. Serves dynamic content to connected browsers.

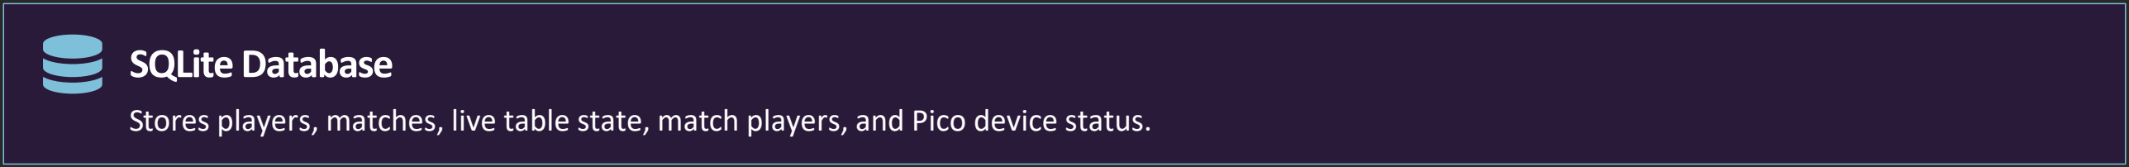
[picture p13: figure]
SQLite Database

Stores players, matches, live table state, match players, and Pico device status.

## Server-Sent Events (SSE)

Pushes live changes from the server to browsers in real time without polling.

# MQTT Communication

### Pico to Server Data Exchange

MQTT is used because it is lightweight and reliable for live embedded data. The topic structure makes it easy to scale.

### Topic Structure

tablefootball/pico/<id>/heartbeat — Pico online status

tablefootball/table/<id>/rfid — Card tap events

tablefootball/table/<id>/state — Score, winner, status

tablefootball/table/<id>/ball — Live pitch position data

Scalable Design: This topic hierarchy makes it easy to add more tables and Picos without changing the server architecture.

QoS Level
0

0

1

1

### MQTT Quality of Service (QoS)

MQTT lets every publish choose a delivery guarantee — trade reliability for speed/overhead.

QoS 0 — "Fire and forget"
Message sent once, no acknowledgment, no retry Fastest, lowest overhead, but a message can be lost.

QoS 1 — "At least once"
Receiver must acknowledge; sender retries until it does Guarantees delivery, but the same message can arrive more than once.

QoS 2 — "Exactly once"
Four-step handshake guarantees delivery with no duplicates Most reliable, but slowest and heaviest. not used in this project

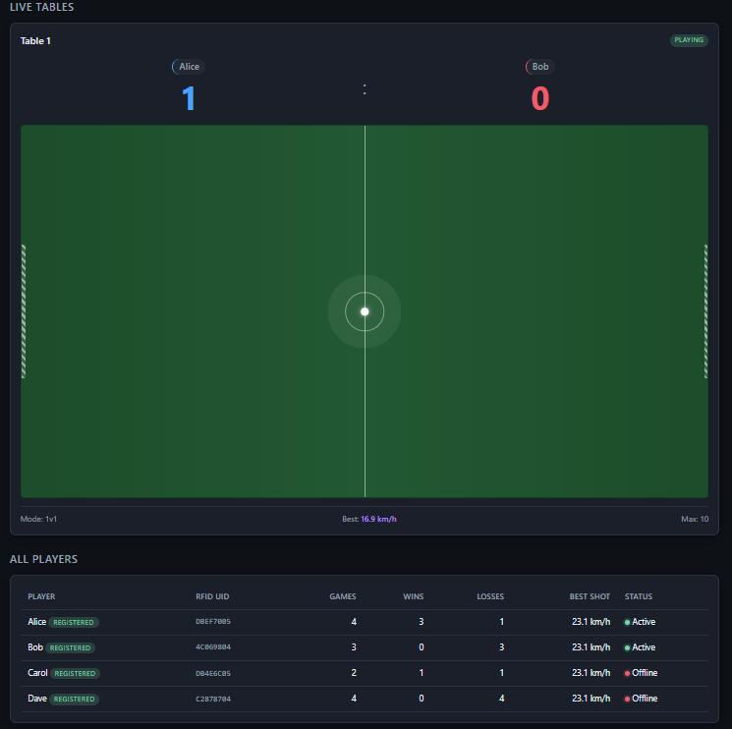
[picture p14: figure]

# Public Dashboard

### Live Match View

## Live Match Cards

Each table displayed as a live match card with player names, guest or registered badges, score, game status, fastest shot, and winner.

## Mini Pitch Visualization

Displays the ball position in real time using the received I2C data. Spectators can follow the action visually.

## Real-Time Updates

Users connect to the Raspberry Pi hotspot and watch the match from any phone or laptop browser. No app installation needed.

# Admin Panel and Player Profiles

### Managing Players and Devices

## Admin Panel Features

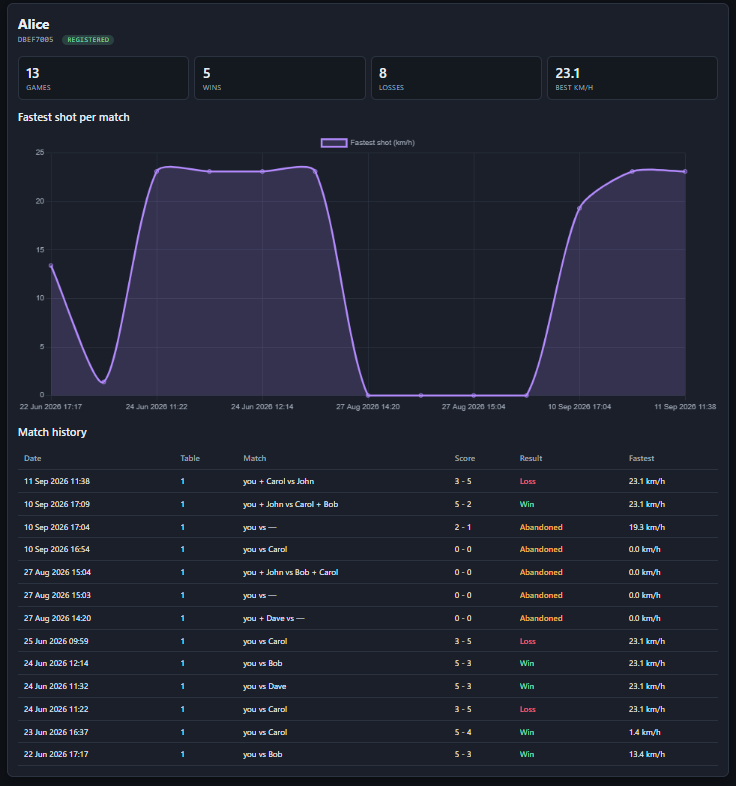
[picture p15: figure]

Player Management: Rename guest players into registered ones once you know who they are..

Pico status monitor & remote control: see which Picos are online/offline, and send Identify, Reset, Clear Players, or a Message to a board.

Table assignment: assign a pico_id to a table_id if a Pico hasn't been linked yet.

## Player Profile Stats

Table & tournament management : create tables and tournaments, generate brackets, assign matches to tables, and start/stop/add/remove players without a card tap.

Authenticated access: protected by a login screen, password set via .env.

# 2v2 & Tournament Mode

### Now Fully Implemented

### 01 Real 2v2 Matches

Either side can hold up to two players; the mode label (1v1/2v2/mixed) is computed automatically from who's seated and shown live on the dashboard.

### 02 Single-Elimination Brackets

An admin creates a tournament, adds entries, and generates a full single-elimination bracket in one click — byes are handled automatically.

### 03 Assign a Match to a Table

Assigning a pending bracket match seats its two entries directly and starts the game — no card tap required to begin.

### 04 Automatic Advancement

The winner of a real, completed match on the assigned table is recorded straight into the bracket, and the next round becomes available automatically.

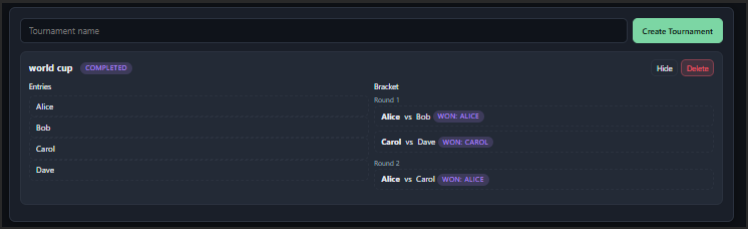
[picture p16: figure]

# Physical Components

### Main Hardware Used

### Pico 2 W

Main embedded controller with Wi-Fi connectivity

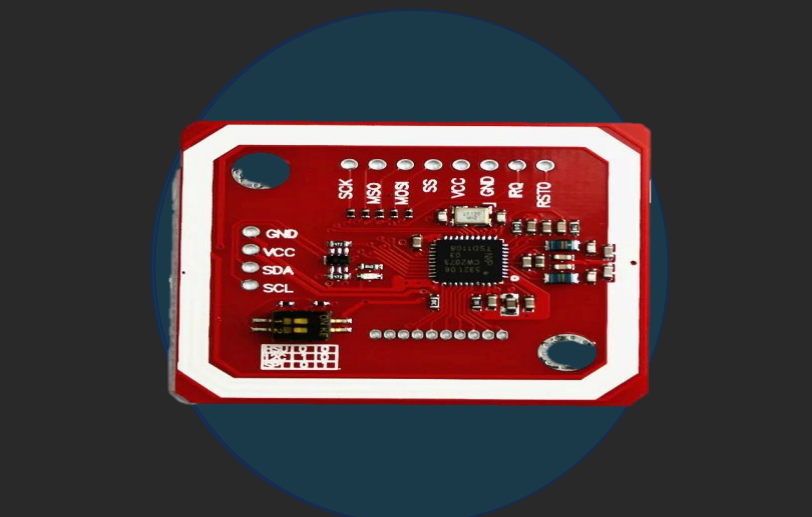
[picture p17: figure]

### PN532 Reader

NFC/RFID card reader for player identification

### EA DOGL128L-6 LCD

Graphic LCD for local score and status display

### Raspberry Pi 4

Central server, MQTT broker, and web dashboard

# Component Roles

### Physical Integration

## PN532 — Player Identification

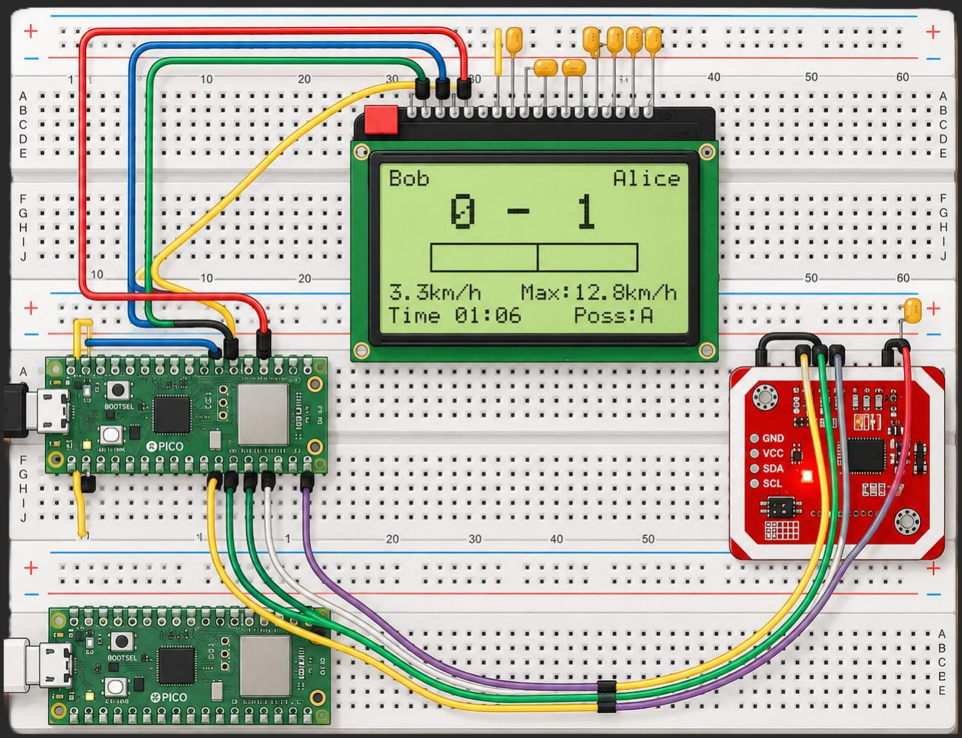
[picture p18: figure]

Reads RFID/NFC cards. Each card UID is treated as a unique player identity.

## EA DOGL128L-6 — Local Feedback

Gives immediate feedback: registration state, player names, score, goal animation, and game-over status.

## I2C Connection — Ball Data

the wired link that carries live ball-position and score data from the camera to the Pico

## Raspberry Pi 4 — Central Server

Dashboard hosting, data storage, and player management hub.

# Hardware Deep-Dive: Custom PCB

### From Breadboard to Fabricated Board

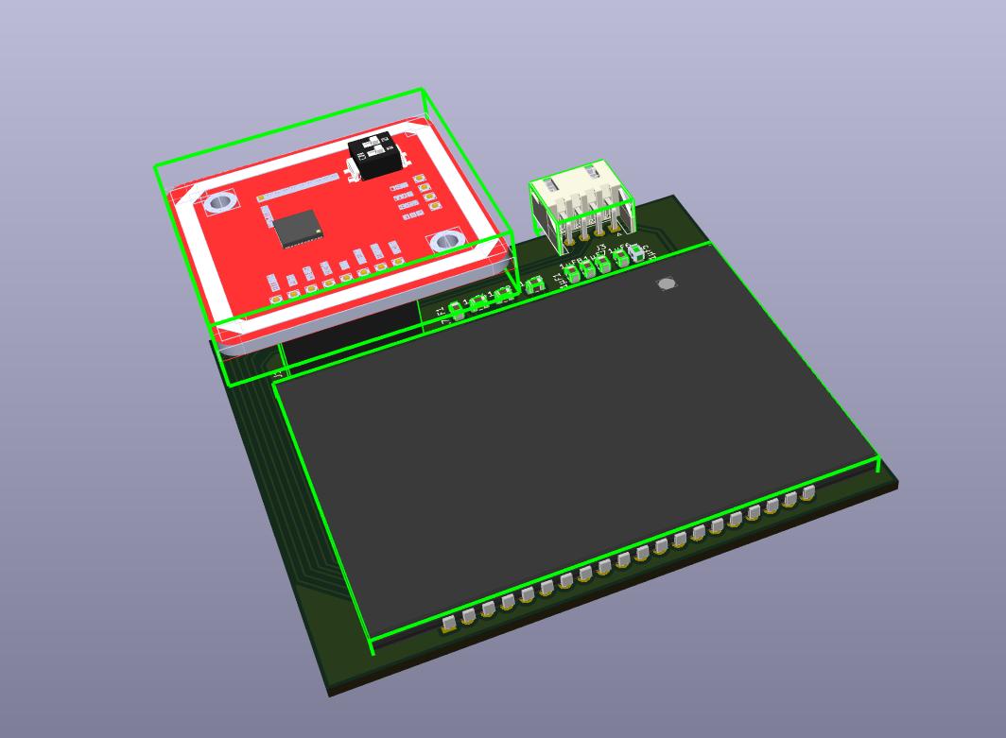
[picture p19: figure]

## Two-Layer Design

The board integrates the Pico 2 W, PN532 reader, and LCD header onto one routed PCB, replacing the original breadboard wiring entirely.

## Decoupling & Power

Eight 1μF ceramic capacitors and a 4.7μF bulk capacitor sit right next to the display header, feeding its charge-pump cleanly.

## I2C Header for the Shared Bus

A dedicated 4-pin connector breaks out SDA/SCL/power to the shared ball-tracker bus, keeping wiring identical on both side-boards.

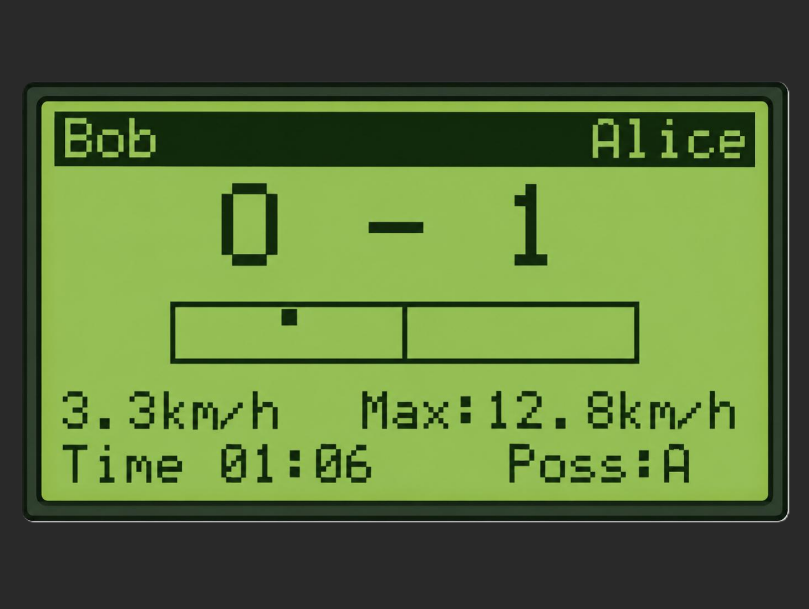
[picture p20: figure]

# Local LCD User Interface

### Feedback on the table, no dashboard needed

The LCD gives players immediate feedback at the table — score, ball position, and match result all update live, with no need to look at a phone or the dashboard.

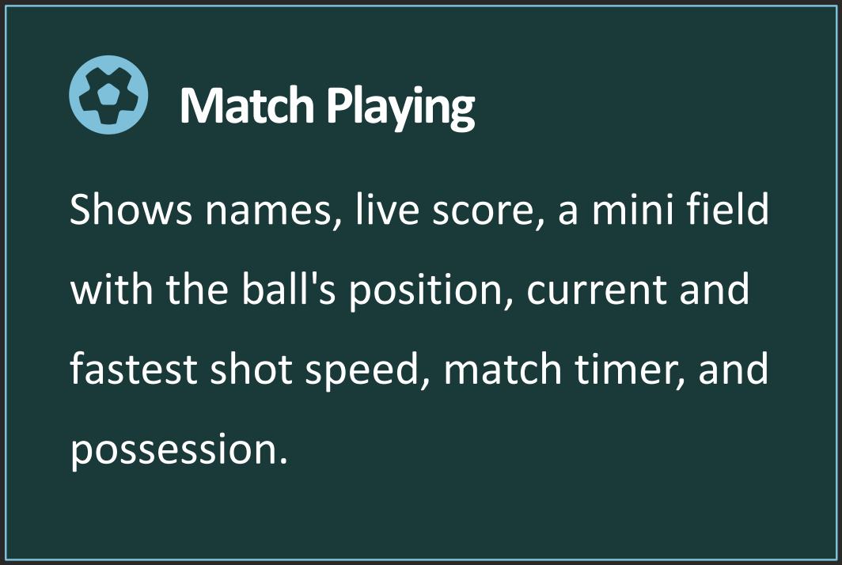
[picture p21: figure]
Match Playing; Shows names, live score, a mini field; with the ball's position, current and; fastest shot speed, match timer, and; possession.

# Physical Enclosure & Deployment

### From Prototype to Cabinet-Ready

## 3D-Printed Enclosure

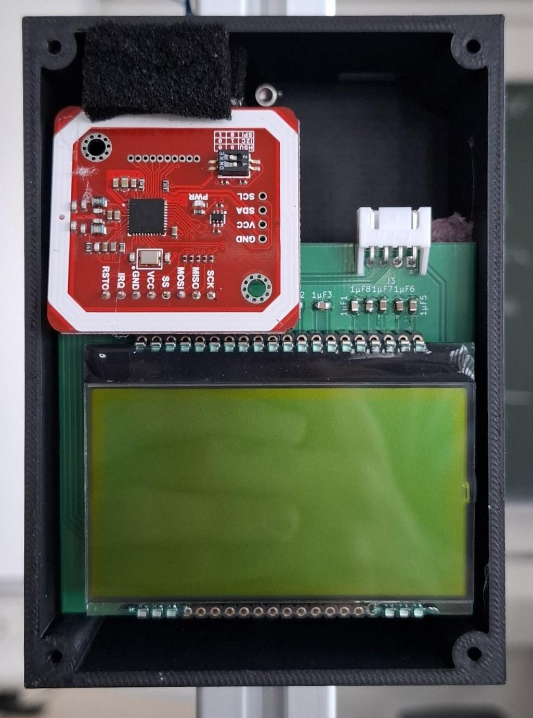
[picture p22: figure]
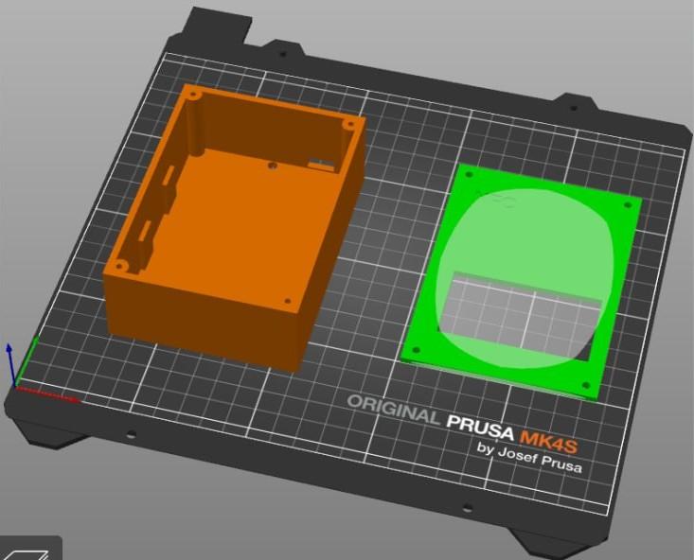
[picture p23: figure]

A enclosed box with a separate front door houses the board, display, and RFID reader, and can be mounted directly onto the table football structure

## Friendly Local URL

The dashboard is reachable at a plain tb.local with no IP address or port number to remember, over the table's own Wi-Fi hotspot.

## Managed as a System Service

The Flask server runs under systemd with automatic restart on failure and a scoped network capability, instead of a manually-started script.

## Remote Board Control

Admins can identify, reset, or message a specific Pico from the dashboard without walking over to the cabinet.

# Remaining Future Work

### Honest Next Steps

01

### Offline Match-History Sync

Offline matches aren't written back to the Pi's database once it reconnects.

02

### Self-Service Player Registration

New players need an admin to register them once, instead of a simple first tap.

03

### Dedicated Pico-to-Pico Link

A dedicated UART or Wi-Fi link between the two boards would remove the current I2C bus-sharing risk entirely.

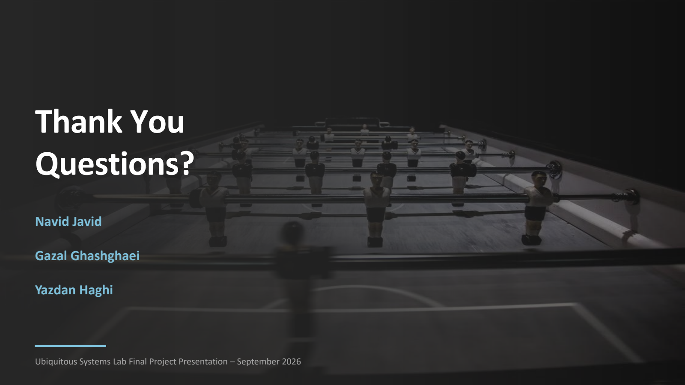
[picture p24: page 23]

# Thank You Questions?

Ubiquitous Systems Lab Final Project Presentation – September 2026

## Navid Javid

## Gazal Ghashghaei

## Yazdan Haghi

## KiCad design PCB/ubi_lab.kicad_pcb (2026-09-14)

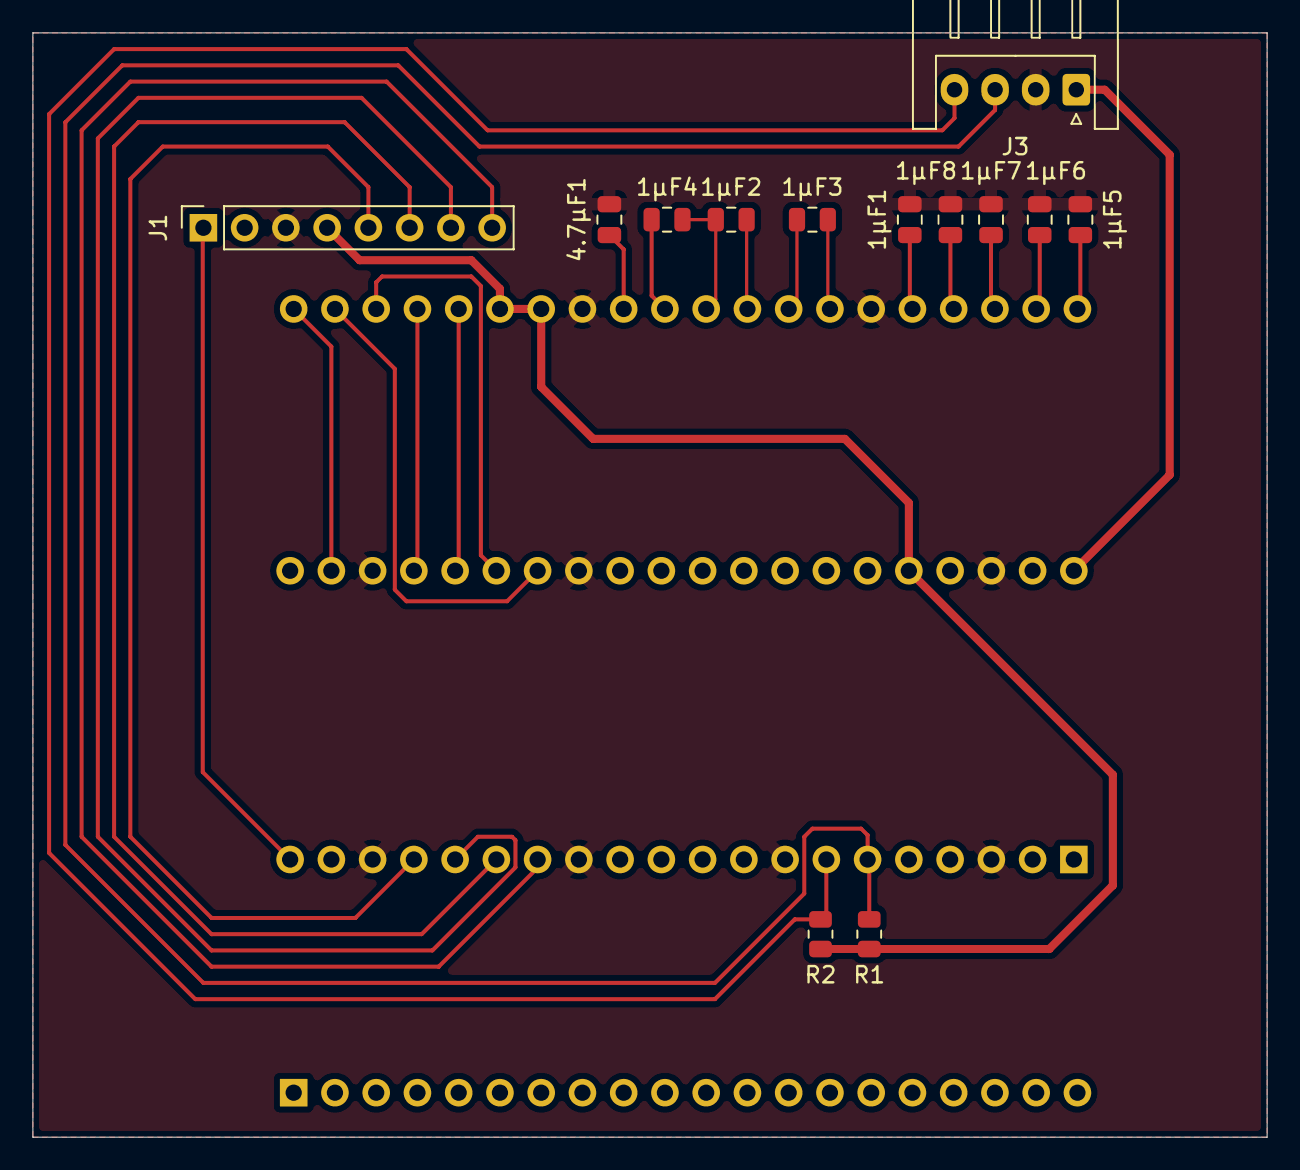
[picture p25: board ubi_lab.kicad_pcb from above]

Board: 2 copper layers, 76.0 x 68.0 mm, 15 parts (1 on the bottom side), 26 nets.

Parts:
1µF1, 1µF2, 1µF3, 1µF4, 1µF5, 1µF6, 1µF7, 1µF8: 1µF; C_0805_2012Metric
4.7µF1: 4.7µF; C_0805_2012Metric
J1: PN532; PinSocket_1x08_P2.54mm_Vertical
J2: EA_DOGL128L_6; EA_DOGL128-6
J3: I2C_SIMULATOR; JST_XH_S4B-XH-A_1x04_P2.50mm_Horizontal
R1, R2: 4.7k; R_0805_2012Metric
U1: RaspberryPi_Pico_W; RaspberryPi_Pico_Socket_THT

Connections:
+3V3: J1.4, J2.34, J2.35, R1.1, R2.1, U1.36 (3V3)
/LCD_A0: J2.38, U1.26 (GPIO20)
/LCD_CAP1N: 1µF2.2, 1µF4.2, J2.30
/LCD_CAP1P: 1µF2.1, J2.29
/LCD_CAP2N: 1µF3.2, J2.27
/LCD_CAP2P: 1µF3.1, J2.28
/LCD_CAP3P: 1µF4.1, J2.31
/LCD_CS: J2.40, U1.22 (GPIO17)
/LCD_MOSI: J2.36, U1.25 (GPIO19)
/LCD_RST: J2.39, U1.27 (GPIO21)
/LCD_SCK: J2.37, U1.24 (GPIO18)
/LCD_V0: 1µF5.1, J2.21
/LCD_V1: 1µF6.1, J2.22
/LCD_V2: 1µF7.1, J2.23
/LCD_V3: 1µF8.1, J2.24
/LCD_V4: 1µF1.1, J2.25
/LCD_VOUT: 4.7µF1.1, J2.32
/RFID_CS: J1.5, U1.17 (GPIO13)
/RFID_MISO: J1.7, U1.16 (GPIO12)
/RFID_MOSI: J1.6, U1.15 (GPIO11)
/RFID_RST: J1.1, U1.20 (GPIO15)
/RFID_SCK: J1.8, U1.14 (GPIO10)
/SCL: J3.4, R2.2, U1.7 (GPIO5)
/SDA: J3.3, R1.2, U1.6 (GPIO4)
GND: 1µF1.2, 1µF5.2, 1µF6.2, 1µF7.2, 1µF8.2, 4.7µF1.2, J1.3, J2.26, J2.33, J3.2, U1.3 (GND), U1.8 (GND), U1.13 (GND), U1.18 (GND), U1.23 (GND), U1.28 (GND), U1.38 (GND)
VBUS: J3.1, U1.40 (VBUS)

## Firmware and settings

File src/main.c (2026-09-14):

#include <stdio.h>
#include <string.h>
#include "pico/stdlib.h"
#include "pico/cyw43_arch.h"
#include "lwip/ip4_addr.h"
#include "lwip/netif.h"
#include "rfid_handler.h"
#include "i2c_comms.h"
#include "game_logic.h"
#include "display_manager.h"
#include "pico_mqtt.h"
#include "player_store.h"

// --- WiFi: join the Pi's hotspot ---
#define WIFI_SSID      "TableFootball"
#define WIFI_PASSWORD  "12345678"

// --- MQTT broker on the Pi itself ---
#define MQTT_BROKER_IP   "192.168.4.1"
#define MQTT_BROKER_PORT 1883

// ---------------------------------------------------------------------------
// Per-board config — final deployment is TWO independent PCBs, one per
// side (own Pico + RFID reader + display each), both reading the same
// shared ball-tracker I2C feed. Flip these three before flashing the
// OTHER side's board:
//   MY_SIDE            'A' on this board, 'B' on the other
//   PICO_ROLE_PRIMARY  1 on exactly ONE board (owns ball+state reporting
//                      to the Pi); 0 on the other (only reports its own
//                      side's RFID taps + heartbeat) — per the agreed
//                      split so the server never gets duplicate/racing
//                      ball or score data from both boards.
//   PICO_ID            must be unique per board
// ---------------------------------------------------------------------------
#define MY_SIDE            'A'
#define MY_SIDE_STR         "A"
#define PICO_ROLE_PRIMARY  1

#define PICO_ID    "pico-side-a"
#define TABLE_ID   1
#define FIRMWARE   "demo-0.3.0"

// Single source for the role label — was duplicated as an inline ternary
// at both the boot log and the heartbeat publish, risking the two
// disagreeing if one call site got edited without the other.
#define ROLE_LABEL (PICO_ROLE_PRIMARY ? "primary" : "secondary")

static char _device_ip[16] = "0.0.0.0";
static char _session_id[40] = "";

static void uid_to_hex(const uint8_t uid[4], char *out /* >= 9 bytes */) {
    snprintf(out, 9, "%02X%02X%02X%02X", uid[0], uid[1], uid[2], uid[3]);
}

static bool hex_to_uid(const char *hex, uint8_t uid_out[4]) {
    if (strlen(hex) < 8) return false;
    for (int i = 0; i < 4; i++) {
        unsigned int byte;
        if (sscanf(hex + i * 2, "%2x", &byte) != 1) return false;
        uid_out[i] = (uint8_t)byte;
    }
    return true;
}

static const char* local_mode_label(const GameData *g) {
    bool a2 = g->side_a[1].filled, b2 = g->side_b[1].filled;
    if (a2 && b2) return "2v2";
    if (!a2 && !b2) return "1v1";
    return "mixed";
}

// ---------------------------------------------------------------------------
// MQTT callbacks. All fire synchronously from cyw43_arch_poll(), same
// thread as main() — safe to touch GameData directly.
// ---------------------------------------------------------------------------
static GameData *_active_game = NULL;

// Temporary full-screen message shown instead of the normal game render —
// used by admin "identify"/"show_message" commands. display_manager_show_
// status() already exists for boot-time status text; reused here rather
// than adding new display code.
static char     _override_msg[64] = "";
static uint32_t _override_until_ms = 0;

// Admin-panel command (Pico Devices controls in the dashboard). The
// server has published to tablefootball/pico/<pico_id>/cmd since it was
// first built, but the firmware never subscribed to it at all — every
// "Identify"/"Reset Match"/"Clear Players"/"Message" button silently did
// nothing on real hardware. This wires it up.
static void on_pi_cmd(const char *cmd, const char *message) {
    printf("[MQTT] Pi cmd: %s\n", cmd);
    if (strcmp(cmd, "identify") == 0) {
        snprintf(_override_msg, sizeof(_override_msg), "ID: %s", PICO_ID);
        _override_until_ms = to_ms_since_boot(get_absolute_time()) + 4000;
    } else if (strcmp(cmd, "show_message") == 0) {
        strncpy(_override_msg, message, sizeof(_override_msg) - 1);
        _override_msg[sizeof(_override_msg) - 1] = '\0';
        _override_until_ms = to_ms_since_boot(get_absolute_time()) + 5000;
    } else if (strcmp(cmd, "reset_match") == 0 || strcmp(cmd, "clear_players") == 0) {
        // GameData doesn't separate "roster" from "match state" — both
        // commands map to the same local reset; the Pi's own DB-side
        // bookkeeping for these two differs, but there's nothing further
        // for this board to do differently between them.
        if (_active_game) game_init(_active_game);
    }
}

// Full registered-player directory from the Pi (retained; sent on every
// heartbeat and via the admin panel's "Sync Players" button). This is
// what lets an offline tap resolve to a REAL registered name instead of
// just the 4-entry hardcoded demo list in game_logic.c — previously the
// "Sync Players" button published this and nothing ever subscribed to
// it, so it did nothing on real hardware. Persisted to flash (see
// player_store.h) so the directory survives a power cycle without
// needing a fresh sync first.
static void on_pi_players_list(const MqttKnownPlayer *players, int count) {
    game_clear_known_players();
    for (int i = 0; i < count; i++) {
        uint8_t uid[4];
        if (hex_to_uid(players[i].uid_hex, uid)) {
            game_set_known_player(uid, players[i].name);
        }
    }
    printf("[MQTT] Known-player directory synced: %d entr%s\n",
           count, count == 1 ? "y" : "ies");
    player_store_save(players, count); // no-op if unchanged from flash
}

// The Pi is the source of truth for player identity; this corrects our
// locally-guessed name (from the hardcoded demo roster in game_logic.c)
// once it resolves OUR OWN tap against its real database. Note: this only
// ever fires for taps THIS Pico published — the sibling board's players
// get their name corrected on the sibling board, not here.
//
// BUG FIXED: this used to always overwrite array index 0 (slot 1) no
// matter which slot the response was actually about. Harmless for 1v1
// (only one slot ever in use), but for 2v2 — once a side has two
// players — resolving the SECOND player's name would blindly stomp the
// FIRST player's name too, since both ended up written to the same
// slot. The server always sends which slot this response is for; use it.
static void on_pi_player(const char *name, const char *side, int slot, bool seated) {
    if (!_active_game || !seated || !name[0]) return;
    if (side[0] != MY_SIDE) return;
    if (slot < 1 || slot > MAX_PLAYERS_PER_SIDE) return;
    PlayerSlot *mine = (MY_SIDE == 'A') ? _active_game->side_a : _active_game->side_b;
    PlayerSlot *target = &mine[slot - 1];
    if (!target->filled) return;
    strncpy(target->name, name, NAME_LEN - 1);
    target->name[NAME_LEN - 1] = '\0';
}

// The other side's board publishes its own RFID taps to this same
// table-scoped topic (we're a subscriber too, same as the server) — this
// is how each board learns the other side's roster without needing to
// wait for a server round-trip. Our own taps also arrive here (echoed
// back) and are ignored since we already applied them locally the
// instant the physical tap happened.
static void on_pi_rfid(const char *side, int slot, const char *uid_hex) {
    (void)slot;
    if (!_active_game || !side[0]) return;
    if (side[0] == MY_SIDE) return;

    uint8_t uid[4];
    if (!hex_to_uid(uid_hex, uid)) return;
    const char *name = game_lookup_player(uid);
    game_register_player(_active_game, side[0], uid, name);
}

// The local SCORE during active play comes from the real-time ball
// sensor (shared by both boards) and is already trusted for gameplay;
// forcibly overwriting it from a retained MQTT snapshot risks a visible
// rollback if the two ever briefly drift, so that part stays hands-off.
//
// Everything else about WHO is seated is only ever known for certain
// through this message. RFID taps only tell a board about players who
// tapped a physical reader; admin add_player/remove_player/start from
// the dashboard produce no RFID tap or ball event at all, so without
// this a board just sits showing stale/empty rosters no matter what the
// admin does. This is the one channel that reaches every case:
//   - admin "reset"/"stop"       -> server reports state=WAITING
//   - admin add/remove a player  -> server's team_a/team_b changes
//   - admin forces a "start"     -> server's state flips with no tap
static void on_pi_sync(const char *state, int score_a, int score_b,
                       const MqttSyncPlayer team_a[2], const MqttSyncPlayer team_b[2]) {
    printf("[MQTT] Pi sync: state=%s score=%d-%d\n", state, score_a, score_b);
    if (!_active_game) return;

    if (strcmp(state, "WAITING") == 0) {
        if (_active_game->state != GAME_WAITING) {
            printf("[MQTT] Pi says table is WAITING (admin reset/stop) -> resetting local game\n");
            game_init(_active_game);
        }
        return;
    }

    for (int slot = 1; slot <= MAX_PLAYERS_PER_SIDE; slot++) {
        const MqttSyncPlayer *a = &team_a[slot - 1];
        const MqttSyncPlayer *b = &team_b[slot - 1];

        uint8_t uid_a[4], uid_b[4];
        bool have_uid_a = a->filled && hex_to_uid(a->uid_hex, uid_a);
        bool have_uid_b = b->filled && hex_to_uid(b->uid_hex, uid_b);

        game_sync_roster_slot(_active_game, 'A', slot, a->filled, a->name,
                              have_uid_a ? uid_a : NULL);
        game_sync_roster_slot(_active_game, 'B', slot, b->filled, b->name,
                              have_uid_b ? uid_b : NULL);
    }
    // An admin-forced registration/start never comes with a local RFID
    // tap to trigger the usual WAITING -> PLAYING check, so do it here
    // too now that the roster above may have just become ready.
    game_recheck_start(_active_game);
}

// ---------------------------------------------------------------------------
// Main
// ---------------------------------------------------------------------------
int main(void) {
    stdio_init_all();
    sleep_ms(2000);
    printf("\n=== Table Football Feedback (side %s, %s) ===\n",
           MY_SIDE_STR, ROLE_LABEL);

    // Display is initialized first so boot progress is visible on the
    // cabinet screen, not just over USB serial. Every status write below
    // happens either before cyw43 starts at all, or in the gap between
    // (not during) a blocking WiFi call — the same "idle WiFi" timing
    // window the original code already relied on for the splash screen
    // that used to run right after WiFi finished. No write ever races an
    // in-progress connect attempt.
    display_manager_init(); printf("[init] Display\n");
    display_manager_show_splash();
    sleep_ms(800);

    // --- WiFi init ---
    // cyw43_arch_wifi_connect_timeout_ms() occasionally reports a timeout
    // right as DHCP is still finishing (association can succeed on the
    // hotspot side a few seconds after the call gives up). Retry a few
    // times, and on a reported failure double-check the actual link/IP
    // state before believing it.
    //
    // Everything past this point must keep working with wifi_ok == false —
    // this cabinet has to run a full local game with no Pi/hotspot present
    // at all, not just tolerate a dead MQTT broker.
    bool wifi_ok = false;
    display_manager_show_status("Connecting WiFi...");
    if (cyw43_arch_init()) {
        printf("[WiFi] init FAILED\n");
        display_manager_show_status("WiFi init failed");
        sleep_ms(1000);
    } else {
        cyw43_arch_enable_sta_mode();

        for (int attempt = 1; attempt <= 3 && !wifi_ok; attempt++) {
            printf("[WiFi] Connecting to '%s' (attempt %d/3)...\n", WIFI_SSID, attempt);
            char status[24];
            snprintf(status, sizeof(status), "WiFi try %d/3...", attempt);
            display_manager_show_status(status);

            int rc = cyw43_arch_wifi_connect_timeout_ms(
                    WIFI_SSID, WIFI_PASSWORD,
                    CYW43_AUTH_WPA2_AES_PSK, 25000);

            int link = cyw43_tcpip_link_status(&cyw43_state, CYW43_ITF_STA);
            const ip4_addr_t *ip = netif_ip4_addr(netif_list);

            if (rc == 0 && link == CYW43_LINK_UP && !ip4_addr_isany(ip)) {
                wifi_ok = true;
            } else if (link == CYW43_LINK_UP && !ip4_addr_isany(ip)) {
                // Reported a timeout/error, but the link actually came up —
                // this is the late-DHCP race described above.
                printf("[WiFi] connect() reported rc=%d but link is up — treating as connected\n", rc);
                wifi_ok = true;
            } else {
                printf("[WiFi] Connection attempt failed (rc=%d), retrying...\n", rc);
                sleep_ms(1500);
            }
        }

        if (wifi_ok) {
            strncpy(_device_ip, ip4addr_ntoa(netif_ip4_addr(netif_list)),
                    sizeof(_device_ip) - 1);
            printf("[WiFi] Connected! IP: %s\n", _device_ip);
            display_manager_show_status("WiFi OK");
        } else {
            printf("[WiFi] Giving up after 3 attempts — running offline\n");
            display_manager_show_status("Offline (no WiFi)");
        }
        sleep_ms(600);
    }

    // --- MQTT --- (best-effort; game must run fine with the Pi absent)
    if (wifi_ok) {
        mqtt_app_init(MQTT_BROKER_IP, MQTT_BROKER_PORT, PICO_ID, TABLE_ID);
        mqtt_app_on_player(on_pi_player);
        mqtt_app_on_sync(on_pi_sync);
        mqtt_app_on_rfid(on_pi_rfid);
        mqtt_app_on_cmd(on_pi_cmd);
        mqtt_app_on_players_list(on_pi_players_list);

        display_manager_show_status("Connecting to Pi...");
        // Bounded wait so a missing/unreachable Pi never delays boot —
        // just enough to show "Connected" if the broker answers quickly.
        uint32_t wait_start = to_ms_since_boot(get_absolute_time());
        while (!mqtt_app_connected() &&
               to_ms_since_boot(get_absolute_time()) - wait_start < 3000) {
            cyw43_arch_poll();
            sleep_ms(50);
        }
        display_manager_show_status(mqtt_app_connected() ? "Pi connected" : "Pi offline (local mode)");
        sleep_ms(600);
    } else {
        display_manager_show_status("Running offline");
        sleep_ms(600);
    }

    // --- Remaining peripherals ---
    rfid_handler_init();    printf("[init] RFID\n");
    i2c_comms_init();       printf("[init] I2C\n");

    display_manager_show_splash();
    sleep_ms(1000);

    GameData  game;
    game_init(&game);
    _active_game = &game;

    // Reload the last-synced player directory from flash, so a board
    // powered on with no Wi-Fi at all this session (not just one that
    // dropped mid-match) still resolves real registered names, not just
    // the hardcoded demo list. Runs regardless of wifi_ok — this is
    // exactly the case it exists for.
    {
        static MqttKnownPlayer loaded[MAX_KNOWN_PLAYERS];
        int n = player_store_load(loaded, MAX_KNOWN_PLAYERS);
        if (n > 0) {
            game_clear_known_players();
            for (int i = 0; i < n; i++) {
                uint8_t uid[4];
                if (hex_to_uid(loaded[i].uid_hex, uid)) {
                    game_set_known_player(uid, loaded[i].name);
                }
            }
            printf("[STORE] Loaded %d known player(s) from flash\n", n);
        }
    }

    BallData  ball       = {0};
    BallData  fresh      = {0};
    GameState prev_state = GAME_WAITING;
    uint32_t  loop       = 0;
    uint32_t  last_heartbeat = 0;
    uint32_t  last_state_pub = 0;
    uint32_t  last_log   = 0;
    uint32_t  boot_ms    = to_ms_since_boot(get_absolute_time());

    while (true) {
        loop++;
        cyw43_arch_poll();  // keep WiFi + lwIP (incl. MQTT) stack alive

        uint32_t now = to_ms_since_boot(get_absolute_time());

        // --- State transition ---
        if (game.state != prev_state) {
            printf("[STATE] %s -> %s\n",
                   game_state_label(prev_state),
                   game_state_label(game.state));
            if (game.state == GAME_PLAYING) {
                i2c_comms_flush();
                printf("[I2C] Buffer flushed\n");
                snprintf(_session_id, sizeof(_session_id),
                        "%s-%lu", PICO_ID, (unsigned long)game.game_start_ms);
            }
            prev_state = game.state;
        }

        // --- I2C (ball tracker feed, shared by both side boards) ---
        i2c_comms_poll(&fresh);
        if (fresh.valid) {
            ball = fresh;
            game_update(&game, &ball);

            // Only the primary board forwards ball telemetry to the Pi —
            // the secondary board still runs the same local game_update()
            // (for its own display/score), it just doesn't publish it.
            if (PICO_ROLE_PRIMARY && game.state == GAME_PLAYING
                && game.field_w > 0 && game.field_h > 0) {
                float x = ((float)game.ball_x / game.field_w) * 1000.0f;
                float y = ((float)game.ball_y / game.field_h) * 500.0f;
                mqtt_publish_ball(TABLE_ID, x, y, game.current_kmh);
            }
        }

        // --- RFID (this board's own reader; always registers to MY_SIDE) ---
        RFIDScanResult rfid;
        rfid_handler_scan(&rfid);
        if (rfid.result == RFID_NEW_TAP) {
            const char *name = game_lookup_player(rfid.uid);
            printf("[RFID] %02X:%02X:%02X:%02X => %s\n",
                   rfid.uid[0], rfid.uid[1],
                   rfid.uid[2], rfid.uid[3],
                   name ? name : "Guest");

            PlayerSlot *mine = (MY_SIDE == 'A') ? game.side_a : game.side_b;
            int next_slot = mine[0].filled ? 2 : 1;

            char uid_hex[9];
            uid_to_hex(rfid.uid, uid_hex);
            mqtt_publish_rfid(TABLE_ID, PICO_ID, MY_SIDE_STR, next_slot, uid_hex);

            // Tell the sibling board directly over the shared I2C bus —
            // the only inter-board link that works with no Pi/WiFi present
            // at all (see i2c_comms.h). MQTT above is best-effort on top
            // of this, not instead of it. Safe to call regardless of game
            // state now: i2c_comms_send_peer_tap() itself waits for a
            // genuinely idle bus before ever touching the I2C peripheral
            // (see i2c_comms.c) — an earlier version of this skipped the
            // call entirely during GAME_PLAYING because the naive
            // deinit/write/reinit dance could wedge the shared bus, but
            // that made mid-game tap-out impossible to propagate, which
            // is required (deregistering mid-match must work offline the
            // same way it already does online via the admin panel).
            i2c_comms_send_peer_tap(MY_SIDE, (uint8_t)next_slot, rfid.uid);

            // game_toggle_player(): tapping an already-seated UID again
            // removes it (offline mirror of the server's own UID-dedup
            // deregister logic in mqtt_client.py's _handle_rfid/_deregister)
            // instead of the old "ignore repeat tap" behavior.
            bool was_playing = (game.state == GAME_PLAYING);
            bool removed = game_toggle_player(&game, MY_SIDE, rfid.uid, name);
            if (removed && was_playing && game_side_empty(&game, MY_SIDE)) {
                // Mirrors the server's own _abandon_match("side emptied") —
                // that happens independently on the Pi (if online) from the
                // mqtt_publish_rfid call above; this is just this board's
                // own local view of the same outcome.
                display_manager_show_status("Match ended - player left");
                sleep_ms(1500);
                game_init(&game);
            }
        }

        // --- Peer taps from the sibling board (same I2C bus) ---
        char peer_side; uint8_t peer_slot; uint8_t peer_uid[4];
        while (i2c_comms_get_peer_tap(&peer_side, &peer_slot, peer_uid)) {
            if (peer_side == MY_SIDE) continue; // shouldn't happen, ignore defensively
            const char *peer_name = game_lookup_player(peer_uid);
            printf("[I2C] Peer tap: side=%c slot=%d\n", peer_side, peer_slot);
            bool was_playing = (game.state == GAME_PLAYING);
            bool removed = game_toggle_player(&game, peer_side, peer_uid, peer_name);
            if (removed && was_playing && game_side_empty(&game, peer_side)) {
                display_manager_show_status("Match ended - player left");
                sleep_ms(1500);
                game_init(&game);
            }
        }

        // --- Display every 250ms ---
        if (loop % 3 == 0) {
            if (_override_until_ms && now < _override_until_ms) {
                display_manager_show_status(_override_msg);
            } else {
                _override_until_ms = 0;
                display_manager_render(&game);
            }
        }

        // --- Heartbeat every 5s ---
        if (now - last_heartbeat > 5000) {
            last_heartbeat = now;
            mqtt_publish_heartbeat(PICO_ID, TABLE_ID, MY_SIDE_STR, ROLE_LABEL,
                                   _device_ip, FIRMWARE,
                                   (now - boot_ms) / 1000);
        }

        // --- Game state to Pi every second — primary board only ---
        if (PICO_ROLE_PRIMARY
            && (game.state == GAME_PLAYING || game.state == GAME_OVER)
            && now - last_state_pub > 1000) {
            last_state_pub = now;
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

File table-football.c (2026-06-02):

#include <stdio.h>
#include <string.h>
#include "pico/stdlib.h"
#include "hardware/spi.h"

// --- Pins ---
#define RFID_SCK  10
#define RFID_MOSI 11
#define RFID_MISO 12
#define RFID_CS   13
#define RFID_RST  15

// --- Registers ---
#define CommandReg    0x01
#define ComIEnReg     0x02
#define ComIrqReg     0x04
#define ErrorReg      0x06
#define FIFODataReg   0x09
#define FIFOLevelReg  0x0A
#define BitFramingReg 0x0D
#define CollReg       0x0E
#define ModeReg       0x11
#define TxControlReg  0x14
#define TxASKReg      0x15
#define TModeReg      0x2A
#define TPrescalerReg 0x2B
#define TReloadRegH   0x2C
#define TReloadRegL   0x2D
#define VersionReg    0x37

spi_inst_t *_spi;

// --- SPI helpers ---
// sleep_us after every access is critical for this RC522 clone
uint8_t read_reg(uint8_t reg) {
    uint8_t tx = ((reg << 1) & 0x7E) | 0x80;
    uint8_t rx = 0;
    gpio_put(RFID_CS, 0);
    sleep_us(5);
    spi_write_blocking(_spi, &tx, 1);
    spi_read_blocking(_spi, 0x00, &rx, 1);
    gpio_put(RFID_CS, 1);
    sleep_us(50);
    return rx;
}

void write_reg(uint8_t reg, uint8_t val) {
    uint8_t buf[2] = { (reg << 1) & 0x7E, val };
    gpio_put(RFID_CS, 0);
    sleep_us(5);
    spi_write_blocking(_spi, buf, 2);
    gpio_put(RFID_CS, 1);
    sleep_us(50);
}

void set_bit(uint8_t reg, uint8_t mask) {
    write_reg(reg, read_reg(reg) | mask);
}

void clear_bit(uint8_t reg, uint8_t mask) {
    write_reg(reg, read_reg(reg) & (~mask));
}

// --- Init ---
void rfid_init() {
    gpio_put(RFID_RST, 0); sleep_ms(50);
    gpio_put(RFID_RST, 1); sleep_ms(50);
    write_reg(CommandReg,    0x0F);   // SoftReset
    sleep_ms(150);
    write_reg(TModeReg,      0x80);
    write_reg(TPrescalerReg, 0xA9);
    write_reg(TReloadRegH,   0x03);
    write_reg(TReloadRegL,   0xE8);
    write_reg(TxASKReg,      0x40);
    write_reg(ModeReg,       0x3D);
    if (!(read_reg(TxControlReg) & 0x03))
        set_bit(TxControlReg, 0x03);
    sleep_ms(50);
}

// --- Transceive ---
uint8_t transceive(uint8_t *send, uint8_t send_len,
                   uint8_t *recv, uint8_t *recv_len) {
    *recv_len = 0;
    write_reg(ComIEnReg,  0xFF);
    write_reg(ComIrqReg,  0x00);
    set_bit(FIFOLevelReg, 0x80);
    write_reg(CommandReg, 0x00);

    for (uint8_t i = 0; i < send_len; i++)
        write_reg(FIFODataReg, send[i]);

    write_reg(CommandReg, 0x0C);
    set_bit(BitFramingReg, 0x80);

    uint8_t n = 0;
    for (int i = 0; i < 300; i++) {
        n = read_reg(ComIrqReg);
        if (n & 0x01) break;   // timer = no card
        if (n & 0x20) break;   // RxIRQ = got data
        sleep_us(100);
    }

    clear_bit(BitFramingReg, 0x80);
    sleep_us(500);

    uint8_t fifo = read_reg(FIFOLevelReg);
    *recv_len = (fifo > 16) ? 16 : fifo;
    for (uint8_t i = 0; i < *recv_len; i++)
        recv[i] = read_reg(FIFODataReg);

    return n;
}

// --- Request: check if card present ---
int request_card(uint8_t *atqa) {
    write_reg(BitFramingReg, 0x07);   // 7-bit frame for REQA
    uint8_t send[1] = { 0x26 };
    uint8_t recv[16];
    uint8_t recv_len = 0;

    uint8_t irq = transceive(send, 1, recv, &recv_len);

    if ((irq & 0x20) || recv_len >= 2) {
        atqa[0] = recv_len > 0 ? recv[0] : 0;
        atqa[1] = recv_len > 1 ? recv[1] : 0;
        return 1;
    }
    return 0;
}

// --- Anticollision: read UID ---
int anticoll(uint8_t *uid) {
    sleep_ms(2);
    write_reg(BitFramingReg, 0x00);
    clear_bit(CollReg, 0x80);

    uint8_t send[2] = { 0x93, 0x20 };
    uint8_t recv[16];
    uint8_t recv_len = 0;

    transceive(send, 2, recv, &recv_len);

    if (recv_len >= 5) {
        uint8_t chk = recv[0] ^ recv[1] ^ recv[2] ^ recv[3];
        if (chk == recv[4]) {
            memcpy(uid, recv, 4);
            return 1;
        }
    }
    return 0;
}

// --- Halt: silence card until removed ---
void halt_card() {
    sleep_ms(2);
    write_reg(BitFramingReg, 0x00);
    uint8_t send[2] = { 0x50, 0x00 };
    uint8_t recv[16];
    uint8_t recv_len = 0;
    transceive(send, 2, recv, &recv_len);
    // After halt, turn antenna off and on to fully reset RF field
    clear_bit(TxControlReg, 0x03);
    sleep_ms(5);
    set_bit(TxControlReg, 0x03);
    sleep_ms(5);
}

int main() {
    stdio_init_all();
    sleep_ms(3000);

    printf("\n=== MFRC522 RFID Reader ===\n");

    _spi = spi1;
    spi_init(_spi, 100 * 1000);
    spi_set_format(_spi, 8, SPI_CPOL_0, SPI_CPHA_0, SPI_MSB_FIRST);
    gpio_set_function(RFID_SCK,  GPIO_FUNC_SPI);
    gpio_set_function(RFID_MOSI, GPIO_FUNC_SPI);
    gpio_set_function(RFID_MISO, GPIO_FUNC_SPI);
    gpio_init(RFID_CS);  gpio_set_dir(RFID_CS,  GPIO_OUT); gpio_put(RFID_CS,  1);
    gpio_init(RFID_RST); gpio_set_dir(RFID_RST, GPIO_OUT); gpio_put(RFID_RST, 1);

    rfid_init();

    printf("Version : 0x%02X\n", read_reg(VersionReg));
    printf("Ready - scan a card...\n");
    printf("---------------------------\n");

    char last_uid[12] = {0};

    while (true) {
        uint8_t atqa[2] = {0};

        if (request_card(atqa)) {
            uint8_t uid[4] = {0};
            if (anticoll(uid)) {
                char uid_str[12];
                snprintf(uid_str, sizeof(uid_str), "%02X%02X%02X%02X",
                         uid[0], uid[1], uid[2], uid[3]);

                // Only print once per tap
                if (strcmp(uid_str, last_uid) != 0) {
                    printf("Card UID: %02X:%02X:%02X:%02X\n",
                           uid[0], uid[1], uid[2], uid[3]);
                    strcpy(last_uid, uid_str);
                }
                halt_card();
            }
        } else {
            // No card in field — reset so next tap prints again
            last_uid[0] = 0;
        }

        sleep_ms(200);
    }
}

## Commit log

2026-06-08 fix bugs and add a demo
    [i2c_comms.c, main.c, rfid_handler.c]
2026-06-10 Add PN532 RFID driver and hardware connection documentation
    - Implemented PN532 driver in C for Raspberry Pi Pico with SPI interface.
    - Added hardware connection documentation for the Table Football Feedback System, detailing connections for PN532 RFID Reader and EA DOGL128L-6 Display.
    - Created test application for PN532 to verify functionality and read card UID.
    - Established I2C communication setup between main and simulator Pico boards.
    - Included power rail summary and software configuration parameters in documentation.
2026-06-22 Add dark theme styles, systemd service, and admin panel
    - Created a new CSS file for dark theme styles to enhance readability.
    - Added systemd service file for running the Flask server under the `pi` user, ensuring it starts after the MQTT broker.
    - Included README for systemd setup instructions.
    - Developed admin panel HTML template for managing Pico devices and players.
    - Implemented admin login page for secure access to the admin panel.
    - Updated main index page to include links to the admin panel and display live tables and player stats.
    - Created player profile page to show detailed player information.
    - Added simulation scripts for testing game functionality, including heartbeat and RF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
2026-06-24 Add MQTT client implementation for Pico
    - Introduced `pico_mqtt.h` and `pico_mqtt.c` to provide a thin wrapper around lwIP's MQTT client.
    - Implemented functions to initialize the MQTT client, check connection status, and publish various message types:
    - Heartbeat messages
    - RFID events
    - Game state updates
    - Ball position updates
    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
2026-08-27 Refactor PN532 SPI communication and add I2C scanning tests
    - Updated the PN532 SPI communication code in test_pn532.c to improve readability and maintainability, including better handling of bit reversal and SPI transactions.
    - Introduced a new I2C bus scanner in test_i2c_scan.c to verify the PN532's aliveness using the I2C protocol, allowing for easier debugging of the chip's functionality.
    - Added a standalone test using the production PN532 driver in test_pn532_lib.c, ensuring compatibility with the existing library and confirming successful card reading.
    [main.c]
2026-09-10 make connection between board in offline mode
2026-09-10 fix bug- dispaly names
    [main.c]
2026-09-10 Fix stale roster/mode bugs, wire up admin cmd topic, clean up dead code
    Turns out the admin panel could leave a table in a weird state depending
    on how a match ended - starting a new one through the admin add-player
    button could inherit the previous match's score and players, since only
    the RFID tap path was clearing that out. Pulled that clearing logic into
    one shared function and used it everywhere a player can get seated.
    Also fixed: admin remove-player never recomputed mode/state when a side
    emptied outside of an active game, admin start left a stale mode from
    the last match, and registering a player through the dashboard wasn't
    pushing the update to the Picos over MQTT (SSE only).
    Big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
    [i2c_comms.c, main.c]
2026-09-11 Retry and log the offline peer-tap I2C send instead of dropping it silently
    Reported symptom: in offline mode (no Pi/WiFi), tapping a card on one
    side never shows up on the sibling board at all - not even as a
    fallback 'Guest', meaning the I2C message itself wasn't getting
    through, not a name-lookup issue.
    i2c_write_timeout_us()'s return value was being thrown away completely,
    so a failed send (NACK, arbitration lost against the ball-tracker's own
    write, bus busy) looked identical to success - the sibling's roster
    just silently never filled in with zero way to tell why. Added a couple
    of quick retries (cheap, since a tap is a one-off low-frequency event)
    and printf logging on both the send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
    [i2c_comms.c]
2026-09-11 Size the peer-tap I2C timeout for a continuously-busy bus, not an idle one
    The camera streams ball data non-stop, so the shared bus isn't
    occasionally busy when a peer-tap wants to send - it's always busy by
    design, with little to no gap between frames. The previous fix (3
    retries at 500us apart, 5ms timeout each) assumed occasional contention
    and would mostly just collide with the same frame every time.
    A 20-byte ball packet takes ~19ms at this bus's 9600 baud, so a single
    attempt now gets a 40ms timeout - long enough to span a full frame and
    land in the gap after its STOP, since the RP2040 I2C hardware itself
    waits for bus-idle before issuing its own START once in master mode.
    Two attempt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
    [i2c_comms.c]
2026-09-11 Fix bug - oflline mode deregistration
    [i2c_comms.c, main.c]
2026-09-11 fix bug - Add board reset functionality before starting new matches and improve simulate_game script
2026-09-14 bug fix - name sync in offline mode
    [main.c]
